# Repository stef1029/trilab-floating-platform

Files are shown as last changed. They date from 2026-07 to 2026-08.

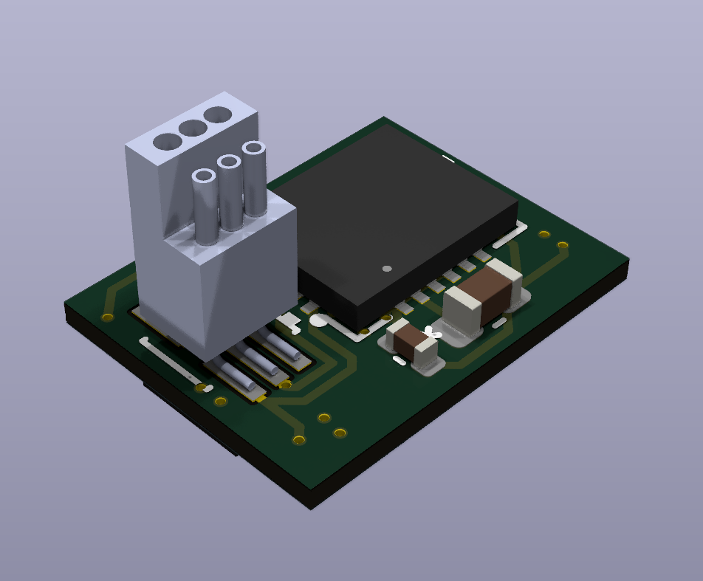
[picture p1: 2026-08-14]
assets/head_sensor_board_3d_model.png

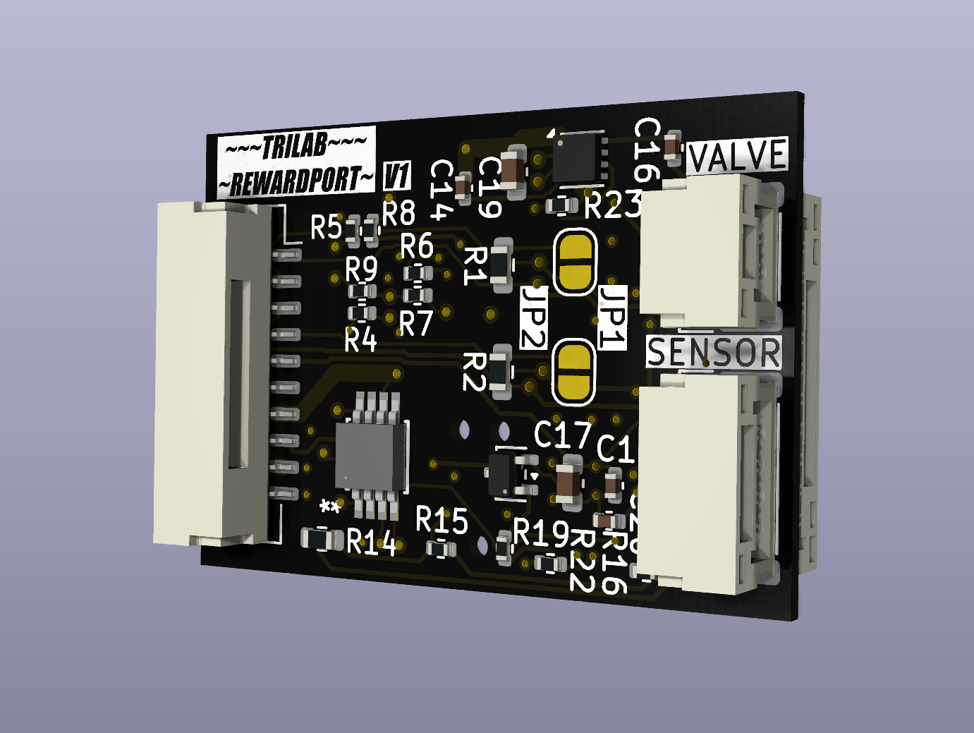
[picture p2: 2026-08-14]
assets/reward_port_3d_model.png

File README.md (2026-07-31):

# Floating Platform Orienting System — Project Specification

A head-fixed behavioural platform for studying sensory-guided spatial orienting in mice.

> **Status:** Design specification and prototyping. This readme defines the scientific intent,
> design principles, and requirements for the system.

---

## 1. Background and Motivation

### 1.1 The problem of spatial orienting

Orienting towards environmental stimuli is a fundamental behaviour conserved across the
animal kingdom: an animal turns its eyes, head, and body to bring a salient stimulus into
its sensory and motor focus. Although subjectively effortless, orienting requires the
nervous system to solve several hard computational problems at once:

- **Coordinate-frame transformation.** Different senses encode space in incompatible
  reference frames (vision in retinotopic coordinates, hearing in head-centred coordinates,
  touch in body-centred coordinates) yet the motor system needs a single unified target.
- **Sensorimotor transformation.** A spatial estimate must be converted into a coordinated
  motor command spanning effectors with very different dynamics (fast, low-range eyes; slower,
  wider-range head; slow, widest-range body).
- **Target selection.** When multiple stimuli compete, the system must commit to a single
  target, the body cannot turn two ways at once.

### 1.2 The superior colliculus (SC)

The SC is an evolutionarily ancient midbrain hub (circuits >500 My old) that sits at the
centre of this problem. It receives topographically aligned, convergent input from
essentially every sensory modality and contains a motor map from which electrical or
optogenetic stimulation reliably evokes orienting movements toward the corresponding
location. Beyond driving movement, accumulating evidence implicates the SC in **spatial
priority / attention**: it is thought to maintain a *priority map* that integrates bottom-up
salience with top-down task relevance, gating both descending orienting commands and
ascending thalamo-cortical signals.

### 1.3 The methodological gap this system addresses

Mouse genetics (Cre-driver lines, optogenetics, optotagging, calcium imaging, two-photon,
high-density electrophysiology) make the mouse SC uniquely tractable for circuit dissection.
But existing mouse paradigms force a trade-off:

| Approach | Strength | Weakness |
|---|---|---|
| **Head-fixed** (2-photon, Neuropixels, VR) | Maximal experimental control, high trial counts, recording/manipulation access | Sacrifices the natural whole-body orienting repertoire; reporting movements are abstract (e.g. licking, wheel turns) |
| **Freely moving** (escape, prey capture, social orienting) | Full natural movement repertoire, ethological validity | Low trial counts, behavioural adaptation/disengagement, hard to standardise and track, limited tool access |

**Design thesis:** a head-fixed preparation that *preserves rotational orienting kinematics*
by mounting the animal on a low-friction, air-floated platform can recover much of the
ethological character of orienting while retaining the recording/manipulation access and
trial structure of head fixation. This is the niche the floating platform system is intended
to fill. Closely related precedents exist in the ferret sound-localisation literature
(approach-to-target paradigms) and in air-lifted platform preparations for rodents; the
novelty here is combining controlled rotational orienting with head fixation and modern
mouse circuit tools.

> **Terminology.** This document follows the *orienting* vs *localisation* distinction
> (Nodal et al., 2008). *Orienting* is the unconditioned, continuously-varying movement of
> eyes/head/body toward a stimulus. *Localisation* (approach-to-target) is the conditioned
> report of perceived location via a discrete choice. This platform is designed to capture
> the **orienting movement itself as a continuous dependent variable**, not merely the
> categorical choice.

---

## 2. Scientific Design Principles

These principles flow directly from the science above and should govern every engineering
trade-off.

1. **Preserve orienting kinematics.** The animal must be able to produce naturalistic
   rotational orienting movements. The platform's mechanics (mass, inertia, friction) must be
   matched to mouse motor capability so that orienting is *natural and low-effort*, not a
   novel motor skill the animal must laboriously acquire. **Movement accessibility is a
   first-order scientific requirement, not an engineering nicety.**

2. **Multiple spatial targets.** Move beyond binary left/right. The animal must be able to
   orient toward stimuli distributed around it, so the system can probe the full spatial map
   of the SC.

3. **Movement as the primary readout.** The dependent variable is the *trajectory* of the
   orienting movement (bearing, latency, amplitude, velocity profile), not just an endpoint.
   This demands continuous, high-resolution measurement of platform orientation.

4. **Multimodal cueing.** Support visual and auditory cues (and ideally the means to add
   somatosensory), so cue modality and coordinate frame can be dissociated — central to
   testing how heterogeneous sensory inputs are transformed into a common motor currency.

5. **Recording- and manipulation-ready from day one.** The system exists to support
   electrophysiology, optogenetics/chemogenetics, and imaging. Compatibility with these tools
   — physical access, electromagnetic compatibility, and above all **temporal
   synchronisation** — must be designed in, not retrofitted.

6. **Trial structure and throughput.** Standardised, self-paced trials with clean
   trial/inter-trial separation, at counts sufficient for statistically powerful,
   circuit-level conclusions.

7. **Respect the animal.** Welfare-conscious head fixation and handling; training timelines
   that are realistic for a cohort within a project's lifetime.

---

## 3. Requirements

### 3.1 Functional requirements (behaviour)

- **F1 — Rotational freedom.** The mouse, while head-fixed, can rotate the floating platform
  beneath it to produce orienting movements through its full natural range, with friction low
  enough that movement is effortless.
- **F2 — Constrained degrees of freedom.** Platform motion is constrained to the behaviourally
  meaningful axes (rotation, translation).
- **F3 — Multi-target cueing.** Present discrete spatial cues at ≥4 (target: 6) locations
  distributed around the animal, with unambiguous angular separation.
- **F4 — Multimodal cues.** Independently addressable **visual** (per-location LED) and
  **auditory** (per-location or spatialised speaker) cue channels; spare capacity for a third
  modality.
- **F5 — Reward delivery.** Precise, low-latency liquid reward (calibrated µL volumes) at each
  target location, with reliable consumption detection.
- **F6 — Response detection.** Detect the animal's chosen orientation/target reliably and with
  low latency (event timing to ≤1 ms), with no false positives/negatives from the sensing
  modality.
- **F7 — Self-paced trial initiation.** A clear, animal-driven readiness/initiation event that
  separates trials from inter-trial intervals and standardises starting conditions.
- **F8 — Configurable protocol.** Cue duration, cue modality, target set, reward contingency,
  timeout, and inter-trial interval all configurable per session and per training phase,
  without code surgery.

### 3.2 Measurement requirements

- **M1 — Continuous orientation tracking.** Platform angular position sampled continuously at
  high temporal resolution (target ≥100 Hz, ideally faster) and angular precision sufficient
  to reconstruct full orienting trajectories — not just endpoints.
- **M2 — Absolute reference where possible.** Orientation measurement should resolve absolute
  bearing (not only relative drift), or provide robust per-trial re-zeroing against a known
  reference event.
- **M3 — Low-light operation.** Behaviour runs under controlled, mouse-appropriate lighting
  (e.g. long-wavelength / IR illumination); the tracking method must work under these
  conditions without motion blur or illumination that interferes with the visual task.
- **M4 — Video record.** Synchronised overhead and/or side video for behavioural scoring and
  markerless pose estimation.

### 3.3 Technical / systems requirements

- **T1 — Unified timing backbone (highest priority).** A single timing authority records all
  event streams — cue onset/offset, reward, response, orientation samples, video frame
  triggers, and external equipment (ephys/laser) sync — on one clock with **≤1 ms** alignment
  across streams. *Lack of hardware-level synchronisation is the single most likely failure
  mode of a behavioural-neuroscience rig and must be solved at the architecture level.*
- **T2 — Drop detection on every stream.** Every data stream (serial messages, camera frames)
  must carry sequence IDs / frame counters so that dropped samples are detectable and
  correctable post-hoc, never silently misaligning data.
- **T3 — External-equipment sync.** Generate and/or record TTL sync with electrophysiology
  acquisition and optogenetic laser control, so neural data and behaviour share a common time
  base.
- **T4 — Electromagnetic compatibility.** Construction and grounding compatible with
  electrophysiology (shielding / Faraday behaviour; low 50 Hz pickup; no conductive paths to
  electrodes).
- **T5 — Deterministic real-time control.** Time-critical operations (reward, response
  sensing, cue timing) handled with deterministic latency; high-level trial logic and logging
  separated from real-time control.
- **T6 — Automated session lifecycle.** One-command session start that configures and launches
  all subsystems (control, acquisition, cameras) in the correct order; automated logging with
  crash recovery.
- **T7 — Standardised, analysis-ready data.** Output to a documented, standard format (e.g.
  NWB) with an accompanying pipeline from raw streams → synchronised, trial-segmented dataset
  → quality-control metrics → figures, minimising manual steps.
- **T8 — Maintainability & reproducibility.** Modular, serviceable hardware (swappable
  per-target modules); liquid-tolerant construction; documented build so additional rigs can
  be replicated by the lab.
- **T9 — Session endurance.** Sustain a full behavioural session (target: continuous operation
  for multi-hour daily use) without power, thermal, or buffer constraints forcing early
  termination.

### 3.4 Non-functional requirements

- **N1 — Welfare.** Graduated head-fixation habituation; comfortable, low-stress fixation;
  bounded session durations.
- **N2 — Trainability.** A naïve mouse should reach criterion performance within a timeframe
  practical for a 10–12 animal cohort. *(Because mechanical accessibility (F1) directly
  governs trainability, the platform's inertia/friction budget should be validated against
  mouse motor output early.)*
- **N3 — Cost & scalability.** Favour designs that allow multiple rigs to run in parallel on
  shared infrastructure without duplicating the most expensive components.

---

## 4. Proposed System Description

A concrete architecture that satisfies the requirements above. Subsystems are described by
*function and constraints*; exact components are deliberately left open where the science does
not yet dictate them.

### 4.1 Mechanical core — the floating platform

- A lightweight, rigid platform (e.g. machined low-density foam) suspended on a **cushion of
  air** above a perforated, regulated air table, giving near-frictionless motion.
- Air supply regulated to lift the loaded platform (platform + onboard electronics) at a
  stable hover height with negligible residual friction.
- **Motion constrained** to the behaviourally relevant axes — primarily rotation (and
  optionally controlled fore/aft translation) — using physical guides, while blocking
  lateral/vertical excursions.
- **Inertia budget:** the rotational moment of inertia of the loaded platform must be small
  relative to the torque a mouse can comfortably generate. This is the central mechanical
  constraint and should be minimised (light platform, minimal onboard mass, balanced about the
  rotation axis) and validated empirically against mouse motor capability before committing.
- A low surrounding wall prevents falls without restricting movement and provides a mounting
  surface for cue/reward modules and/or tracking references.

### 4.2 Head-fixation assembly

- Standard, welfare-conscious head-bar fixation (off-the-shelf optomechanics) positioning the
  animal centrally over the platform's rotation axis, leaving the body free to drive platform
  rotation.
- Fixation height and posture chosen so that orienting is produced by natural weight-shift /
  stepping, not an artificial motor strategy.

### 4.3 Target / cue / reward modules

- A ring of **modular, independently serviceable target stations** at fixed angular intervals
  (target: 6 at 60°, minimum 4 at 90°).
- Each station integrates: a **visual cue** (high-brightness LED), an **auditory cue**
  (speaker), a **liquid reward** spout (solenoid/pinch-valve, gravity- or pump-fed, calibrated
  volume), and a **response/consumption sensor** (e.g. IR beam-break — preferred over
  capacitive sensing for reliability).
- Modularity allows a faulty station to be swapped without disturbing the rig and supports
  rapid prototyping of new configurations.

### 4.4 Orientation tracking

Continuous platform-orientation measurement is mandatory (M1–M3). The architecture should
support — and ideally fuse — complementary methods, chosen for robustness under low-light
operation:

- An **inertial measurement unit (IMU)** mounted on the platform for high-rate relative
  orientation, re-zeroed each trial against a known reference event (giving high within-trial
  accuracy).
- And/or an **absolute optical reference** (e.g. fiducial markers read by a camera, or an
  optical/magnetic angular encoder on the rotation axis) for absolute bearing and drift
  correction — noting that any camera-based method must tolerate the IR/low-light regime and
  platform motion without blur.
- **Markerless pose estimation** (e.g. DeepLabCut) on synchronised video as an independent
  cross-check and for body/limb kinematics.

### 4.5 Control and acquisition architecture

The defining architectural commitment: **separate real-time control from timing/logging.**

- **Real-time controller** (microcontroller): owns deterministic, time-critical hardware
  control — cue timing, reward actuation, response sensing — and nothing else. Prefer a
  microcontroller with **native USB** (low, deterministic serial latency) over legacy
  serial-to-USB bridges.
- **Independent acquisition / timing backbone (DAQ):** a dedicated device that does nothing
  but sample *all* digital/analogue lines (cue states, sensor states, reward signals) plus
  external sync (camera frame TTLs, ephys clock, laser control) at high rate (target ≥1 kHz,
  ideally ≥10 kHz) onto **one clock**. Every message carries a sequence ID (T2).
- **Host computer:** runs high-level trial logic / state machine, configuration, multi-rig
  orchestration, real-time performance metrics, and all file writing (offloading I/O from
  embedded devices). Launches the whole session with one command (T6).
- **Cameras:** programmatically controlled (not via a GUI), emitting a TTL per frame into the
  DAQ and saving hardware frame IDs, so dropped frames are detectable and video aligns to the
  behavioural timeline to the frame.

This separation is what delivers T1–T3: a single timestamped record into which neural,
video, and behavioural events all map without clock drift.

### 4.6 Software, data, and analysis pipeline

- **Configurable protocol engine** encoding training phases and trial parameters via
  configuration, not code edits (F8).
- **Standardised output** (NWB or equivalent) bundling synchronised event streams, orientation
  traces, video references, and trial metadata, with crash-recovery/backup.
- **Automated post-processing**: parse DAQ logs → reconstruct trials → align video via frame
  IDs → run pose estimation → emit a trial-segmented dataset plus QC metrics, with minimal
  manual intervention.
- **Cohort/session data model** giving programmatic access (query by animal, date, completion
  status) so analyses run over whole cohorts in little code.

### 4.7 Behavioural protocol (intended)

1. **Initiation.** The animal produces a defined, self-paced readiness event that standardises
   the starting orientation and separates trials from inter-trial intervals (F7). The
   initiation requirement must be designed to genuinely standardise starting conditions
   (minimising preparatory movement before cue onset).
2. **Cue.** One target is cued (visual and/or auditory), with configurable duration.
3. **Orienting response.** The animal rotates the platform to bring the cued target into
   reach; the full trajectory is recorded.
4. **Outcome.** Correct orientation → immediate calibrated reward. Incorrect → brief timeout,
   no reward.
5. **Reset.** Return to initiation for the next self-paced trial.

---

## 5. Key Open Design Questions / Risks

Flagged up front because they drive the riskiest decisions:

- **Mechanical accessibility vs. control (F1/N2).** Can the inertia/friction budget be made
  low enough that a head-fixed mouse produces natural orienting rotations *and* learns the task
  in a cohort-feasible timeframe? This is the make-or-break biological-mechanical question and
  should be de-risked first with simple motor-capability tests.
- **Tracking under low light (M1–M3).** Reconciling absolute, blur-free, high-rate orientation
  measurement with the dim/IR lighting the visual task requires. IMU + absolute-encoder fusion
  is the conservative hedge.
- **Initiation standardisation (F7).** Defining an initiation behaviour that truly fixes
  starting orientation without permitting covert preparatory movement.
- **Synchronisation throughput (T1).** Achieving the target sample/frame rates without
  message loss; choice of controller and DAQ should leave headroom above the minimum.

---

## 6. Key References

Foundational citations that justify the design intent.

**Superior colliculus, orienting, and spatial priority**
- May, P. J. (2006). The mammalian superior colliculus: laminar structure and connections.
  *Prog. Brain Res.* 151. — SC anatomy and laminar organisation.
- Sparks, D. L. & Mays, L. E. (1990). Signal transformations required for the generation of
  saccadic eye movements. *Annu. Rev. Neurosci.* 13. — SC sensorimotor transformation.
- Fecteau, J. H. & Munoz, D. P. (2006). Salience, relevance, and firing: a priority map for
  target selection. *Trends Cogn. Sci.* 10. — priority-map concept.
- Krauzlis, R. J., Lovejoy, L. P. & Zénon, A. (2013). Superior colliculus and visual spatial
  attention. *Annu. Rev. Neurosci.* 36. — SC role in attention beyond movement.
- Knudsen, E. I. (2018). Neural circuits that mediate selective attention: a comparative
  perspective. *Trends Neurosci.* 41. — gating and selective attention.
- de Malmazet, D. & Tripodi, M. (2023). Collicular circuits supporting the perceptual, motor
  and cognitive demands of ethological environments. *Curr. Opin. Neurobiol.* 82.
- Masullo, L. et al. (2019). Genetically defined functional modules for spatial orienting in
  the mouse superior colliculus. *Curr. Biol.* 29. — Pitx2+ SC output neurons; target
  population for manipulation.

**Behavioural paradigms and precedents**
- Parsons, C. H., Lanyon, R. G., Schnupp, J. W. H. & King, A. J. (1999). *J. Neurophysiol.* 82.
  — ferret sound-localisation / approach-to-target precedent.
- Nodal, F. R. et al. (2008). Sound localisation behaviour in ferrets: acoustic orientation vs
  approach-to-target. *Neuroscience* 154. — the orienting vs localisation distinction.
- Robbins, T. W. (2002). The 5-choice serial reaction time task. *Psychopharmacology* 163. —
  multi-choice spatial reporting paradigm.
- Guo, Z. V. et al. (2014). Procedures for behavioral experiments in head-fixed mice. *PLoS
  ONE* 9. — head-fixed behavioural standards.
- Kislin, M. et al. (2014). Flat-floored air-lifted platform: combining behaviour with
  microscopy/electrophysiology on awake freely moving rodents. *JoVE*. — air-lifted platform
  precedent.
- Angelaki, D. et al. (2025). A brain-wide map of neural activity during complex behaviour.
  *Nature* 645. — mice performing complex standardised tasks.

**Tools and infrastructure**
- Denman, D. J. et al. (2017). Chromatic pathways in the mouse dLGN. *J. Neurosci.* 37. —
  basis for long-wavelength lighting choices for mouse vision.
- Mathis, A. et al. (2018). DeepLabCut: markerless pose estimation. *Nat. Neurosci.* 21.
- Rübel, O. et al. (2022). The Neurodata Without Borders ecosystem. *eLife* 11. — standardised
  data format.

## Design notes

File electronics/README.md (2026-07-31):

# Electronics

KiCad projects, schematics, PCB layouts, BOMs, and fabrication outputs.

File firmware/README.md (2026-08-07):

# Korora Fairy system

This project contains contains firmware for one Korora, one Galapagos, and a configurable number of Fairy boards. It also contains the Adelie Python application and the shared wire protocol library.

The default maximum is six Fairy boards. Change `FAIRY_MAX_BOARDS` in `shared/include/fairy_shared/system_config.hpp` or pass it as a build definition.

## Naming conventions

| Implementation name | Role | Board |
| --- | --- | --- |
| Korora | Floating platform hub | nRF52840 |
| Fairy | Reward port | STM32G071\* |
| Galapagos | Static DAQ TTL sync | nRF54L15 |

| Protocol name | Layer | Use |
| --- | --- | --- |
| Fairy protocol | Application | Defines structure of records that are collected and used for later analysis |
| Adelie protocol | Application | Defines structure of commands being issued for interaction with peripherals, generating TTLs... |
| Magellan protocol  | Application | Defines process and structure of assinging logical addresses to fairy boards |
| Transport protocol | Transport | Defines the structure of frames being sent over various media (UART, BLE) |

## System structure

```mermaid
flowchart TD
    A["Adelie Python application"] <-->|"BLE transport"| K["Korora nRF52840"]
    K <-->|"BLE transport"| G["Galapagos nRF54L15"]
    K <-->|"RS485 transport"| F["Fairy boards"]
    K -->|"4 Hz SYNC"| F
    G -->|"TTL loopback"| K
```

Korora is the time authority and the only RS485 bus master. Galapagos creates scheduled TTL pulses. Fairy boards capture light gate and SYNC edges and drive the local outputs. Adelie assigns board names, sends commands, displays live quality, and writes experiment records.

All machine data uses one of these application protocols:

- Fairy v3 for records
- Adelie v2 for commands and responses
- Magellan v1 for discovery and address assignment

The application messages always use Transport v1 on BLE or RS485. Human debug text is isolated in each `debug_log` module and is never parsed by the system.

## Folders

| Folder | Purpose |
| --- | --- |
| `shared` | C++ transport, protocol, clock, queue, and byte utilities |
| `korora` | Zephyr firmware for the nRF52840 hub |
| `galapagos` | Zephyr firmware for the nRF54L15 TTL board |
| `fairy` | STM32Cube and PlatformIO firmware for STM32G071 boards |
| `adelie` | Python 3.14 control, recording, parsing, analysis, and plotting |
| `docs` | Wire protocol specifications and operating rules |

## Fixed timing values

| Setting | Value |
| --- | ---: |
| Common timestamp rate | 16000000 ticks per second |
| SYNC rate | 4 Hz |
| RS485 baud | 460800 |
| RS485 format | 8 data bits, no parity, 1 stop bit |
| Fairy TIM2 rate | 16 MHz |
| Prototype VLOAD | 5000 mV |

One timer tick is 62.5 ns.

## Build summary

Use a current Zephyr or nRF Connect SDK workspace for the Nordic firmware.

```bash
west build -p always -b nrf52840dk/nrf52840 korora
west flash
```

```bash
west build -p always -b nrf54l15dk/nrf54l15/cpuapp galapagos
west flash
```

Build the prototype Fairy firmware with PlatformIO.

```bash
pio run -d fairy -e nucleo_g071rb_auto_rs485
pio run -d fairy -e nucleo_g071rb_auto_rs485 -t upload
```

Install Adelie in a Python 3.14 virtual environment.

```bash
cd adelie
python -m venv .venv
python -m pip install -e .
adelie
```

## Initial setup

1. Power Korora, Galapagos, and all Fairy boards
2. Start Adelie and connect to Korora
3. Wait for the complete UUID inventory
4. Use White LED to identify each board
5. Give each UUID a unique zero based Fairy index
6. Save the exact configuration
7. Wait for every clock model to become valid
8. Choose a new `.log` path
9. Press Record Start

Adelie applies saved assignments automatically only when the complete discovered UUID set exactly matches the saved set. A missing, added, or replaced board returns the user to configuration.

## Run behavior

Korora starts discovery, health checks, RS485 polling, and SYNC without Adelie. It does not save experiment data.

Record Start creates a session on every board. An unexpected Adelie disconnect ends that session and turns controlled outputs safe. Discovery, SYNC, and health work continue until power is removed.

A Fairy communication timeout or a Galapagos disconnect also ends the complete session. The fault is sent to Adelie before the remaining boards are stopped.

Critical records are always forwarded. Standard mode adds health and clock quality. Full mode adds raw SYNC observations and clock pairs.

## Safety

The valve starts off and has a hard 250 ms maximum time. It rejects overlap and enforces a minimum interval. RGB, IR, audio, and valve outputs enter safe states on reset and session stop. Audio has a 10 ms onset and offset ramp. The prototype configuration assumes automatic RS485 direction control. Korora and the Nucleo profile do not drive a direction GPIO.

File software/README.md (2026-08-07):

# Adelie Python application

Adelie is the universal host application for board setup, live control,
recording, static analysis, and plotting. It is written for Python 3.14 and
also supports Python 3.11 or newer.

## Features

- Bleak connection to Korora
- Modern PySide6 interface
- One live card per Korora, Galapagos, and Fairy
- Live RMS history, skew, record rate, queue, loss, and RSSI
- Exact UUID configuration saved as JSON
- White LED board identification
- RGB, IR, tone, white noise, and valve controls
- Telemetry level selection
- Scheduled TTL train control
- One button sync test
- One locked JSON Lines log writer
- Static parser, analyser, and plotter

## Install

```bash
python -m venv .venv
python -m pip install --upgrade pip
python -m pip install -e .
```

Run:

```bash
adelie
```

Optional paths:

```bash
adelie --config config/boards.json --recordings recordings
```

## Board configuration

Adelie requests the full live inventory after BLE connects.

When the saved UUID set matches exactly, Adelie sends the saved Fairy indices
to Korora. When it differs, the table remains in configuration mode.

To create a configuration:

1. Click White LED on one row
2. Find the board showing white
3. Enter its zero based Fairy index and label
4. Repeat for every row
5. Save the exact UUID configuration

The JSON file is the backup. Korora stores no assignment across a power cycle.

If any live UUID is added, missing, or replaced, automatic assignment stops.

## Recording

Choose the `.log` path before Record Start. The recorder creates a new file
and refuses to overwrite an existing file.

Each line is one JSON value. The file contains:

- Header with protocol versions and UUID mapping
- Every Fairy record received during the session
- Raw application message in Base64
- Host monotonic receive time
- Footer with stop reason

Nothing is written before Record Start. An unexpected BLE disconnect closes
the file with a footer when the process still has control.

Record Stop keeps the writer open briefly after the stop response so final
output off records can arrive. A Fairy inventory change or a critical hardware
fault requests the same orderly stop.

## Telemetry

Critical mode keeps experiment events and faults.

Standard mode also keeps health, inventory, link, and clock quality.

Full mode also keeps every raw SYNC observation and clock pair. Test sync
selects full mode, sends safe random RGB commands, and starts TTL at 1 Hz.

## Static tools

Run the full pipeline:

```bash
adelie-run-analysis recordings/run_20260730_120000.log
```

Or run each stage:

```bash
adelie-parse RUN.log
adelie-analyse RUN_parsed
adelie-plot RUN_parsed
```

The parser creates:

- `records.csv`
- `commands.csv`
- `command_results.csv`
- `sync_pairs.csv`
- `sync_quality.csv`
- `ttl.csv`
- `events.csv`
- `health.csv`
- `manifest.json`

The analyser creates:

- `node_summary.csv`
- `command_summary.csv`
- `prediction_errors.csv`
- `ttl_results.csv`
- `summary.json`
- `summary.txt`

The plotter creates synchronization, per node prediction error, command RTT,
and TTL alignment PNG files when the required records exist.

Every parsed record includes its numeric logical address, logical node name,
saved label, and Fairy index. For example, address `0x10` is reported as
`fairy0` rather than a generic node number.

`commands.csv` contains one row per Adelie command with:

- Time waiting in the host transmit queue
- Queue to response RTT
- Actual BLE send to response RTT
- Destination logical node
- Opcode and response status
- Missing response detection
- Matching command result count and result nodes
- Clock exchange full RTT, Korora processing time, and network RTT

`command_results.csv` matches Fairy command result records back to the Adelie
command ID and reports them separately for every logical Fairy.

Command timing fields are available only in logs recorded with this version of
Adelie. Older logs did not store outbound command or response timestamps, so
their command RTT cannot be reconstructed.

## Log recovery

Every record is one complete flushed line. If the host loses power, valid
lines before the partial final line remain usable. The parser reports the
line number of malformed JSON so a partial last line can be removed without
changing earlier data.

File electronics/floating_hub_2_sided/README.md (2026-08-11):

# Korora Hub

Central nRF52840-based hub board for the behavioural rig. Korora provides:

- RS-485 master communication to peripheral boards
- Differential SYNC distribution to peripheral boards
- System time authority and synchronization
- 9-DoF motion/orientation sensing
- LiPo battery charging and power-path management
- Battery / power telemetry to the nRF52840
- 3V3 and VLOAD distribution over the peripheral harness
- USB/SWD-style development and debug access as appropriate for the final PCB

The current controller module is the BMD-340-A-R, based on the nRF52840.

The current power-management assumption is an nPM1300-class Nordic PMIC. Exact PMIC variant, battery connector, thermistor arrangement, charge current, and rail configuration must be finalized against the selected battery before schematic release.

## System architecture

Korora is the system master.

The hub:

- owns the system timebase
- initiates RS-485 transactions
- emits the differential SYNC signal
- gathers peripheral event timestamps
- translates peripheral-local timestamps into hub/system time
- acquires the local IMU and magnetometer
- runs or hosts the 9-DoF orientation-fusion algorithm
- monitors battery and power state
- distributes 3V3, VLOAD, and ground to the peripheral chain

Initial high-level architecture:

```text
                         +----------------------+
5V BENCH INPUT --------->|                      |
                         |       nPM PMIC       |
LiPo BATTERY ----------->| charger / fuel gauge|
                         | power-path / bucks   |
                         +----+-------------+---+
                              |             |
                             3V3           VSYS
                              |             |
                              |             +---------- VLOAD
                              |                         |
                              +-------------------------+--> JST-GH
                              |
                    +---------+---------+
                    |    BMD-340-A-R    |
                    |      nRF52840     |
                    +----+----+----+----+
                         |    |    |
                      UART   GPIO  I2C/SPI
                         |    |    |
                         |    |    +----> IMU
                         |    |    +----> magnetometer
                         |    |    +----> PMIC telemetry
                         |    |
                         |    +---------> SN65HVD75 #2
                         |                  SYNC_P/N
                         |
                         +-------------> SN65HVD75 #1
                                            RS485_P/N
```

## Relationship to peripheral boards

Korora is designed to connect directly to peripheral boards using the common 10-pin JST-GH bus.

Korora is the RS-485 bus master and the source of the differential SYNC pulse. Peripheral boards are expected to:

- listen for hub commands
- transmit only when addressed
- capture SYNC locally in hardware
- report captured timestamps and local events back to Korora

The initial Reward Port design assumes a 500000 baud, 8-N-1, half-duplex RS-485 link and an initially 4 Hz SYNC pulse.

These values are initial protocol parameters rather than permanent electrical limitations.

## Power inputs

Korora has two power sources:

1. LiPo battery
2. External 5 V bench / development supply

The PMIC provides charging and power-path control between them.

### Battery input

The earlier system requirement described the battery as approximately 4.3 V.

Do not set the PMIC charge termination voltage from that description alone. The final battery datasheet controls:

- maximum charge voltage
- charge current
- temperature limits
- NTC requirements
- minimum discharge voltage
- protection requirements

### Bench power input

Provide a 2-pin header for development power:

| Pin | Signal |
| --: | --- |
| 1 | +5V_BENCH |
| 2 | GND |

The bench input feeds the PMIC input rather than directly feeding the battery rail.

Intended behaviour:

```text
5 V bench present
        |
        v
      PMIC
      /  \
     /    +----> system load
    |
    +---------> battery charging
```

The bench supply must be current limited during initial bring-up.

## Power rails

Korora distributes two positive rails to the peripheral connector.

### 3V3

3V3 is the regulated digital rail.

Expected loads include:

- BMD-340-A-R
- RS-485 transceivers
- local sensors
- PMIC digital interface as required
- peripheral-board 3V3 loads through the JST-GH chain

The total required 3V3 current is TBD.

Before finalizing the PMIC configuration, calculate:

```text
hub local 3V3 load
+
maximum number of peripheral boards
x
maximum peripheral 3V3 load
=
required regulated 3V3 current
```

If this exceeds the useful continuous current available from the selected PMIC regulator configuration, Korora requires an external 3V3 regulator or a revised power architecture.

### VLOAD

VLOAD is currently defined as the PMIC system / VSYS rail.

VLOAD is not assumed to be a precision regulated 5 V rail.

Conceptually:

```text
battery operation:
battery -> PMIC power path -> VSYS -> VLOAD

bench operation:
5 V input -> PMIC power path -> VSYS -> VLOAD
```

Therefore VLOAD may vary with power-source state and battery condition.

Peripheral loads must be designed for the specified VLOAD operating range.

The final VLOAD voltage range and current limit must be documented after the PMIC and battery design are finalized.

## PMIC interface

Korora should provide a digital control / telemetry link between the PMIC and the nRF52840.

Current intended interface:

```text
BMD-340 SDA <------> PMIC SDA
BMD-340 SCL -------> PMIC SCL
PMIC IRQ ----------> BMD-340 GPIO
```

The firmware should be able to query and log, where supported by the selected PMIC configuration:

- battery voltage
- battery current
- input-source state
- charging state
- state of charge
- battery health / aging information
- PMIC fault state
- regulator state
- power-loss or low-battery warnings

Exact registers and reported metrics depend on the final PMIC implementation.

## Main controller

Controller module:

```text
BMD-340-A-R
nRF52840
```

Korora uses the nRF52840 for:

- system timing
- RS-485 protocol
- SYNC generation
- peripheral discovery and polling
- event collection
- sensor acquisition
- sensor fusion
- battery telemetry
- BLE / radio functionality if required
- diagnostics
- firmware update / development functions

## BMD-340 pin assignment

Physical BMD-340 pin numbers are not yet frozen.

Reserve logical functions for:

| Function | Peripheral / type | Notes |
| --- | --- | --- |
| RS-485 transmit | UARTE TX | Main peripheral bus |
| RS-485 receive | UARTE RX | Main peripheral bus |
| RS-485 driver enable | GPIO or UARTE DE strategy  | Must default bus-safe |
| SYNC output | GPIO / timer-driven output | Feeds second RS-485 driver |
| PMIC SDA | TWIM / I2C | Shared bus possible |
| PMIC SCL | TWIM / I2C | Shared bus possible |
| PMIC interrupt | GPIO input | Optional but recommended |
| IMU bus | SPI or I2C | Final choice TBD |
| IMU interrupt 1 | GPIO input | Data-ready / FIFO event |
| IMU interrupt 2 | GPIO input | Optional |
| Magnetometer bus | I2C or SPI | Final choice TBD |
| Magnetometer DRDY | GPIO input | Optional but recommended |
| SWDIO | SWD | Debug |
| SWDCLK | SWD | Debug |
| RESET | reset | Debug / recovery |

The final pin assignment should be chosen only after confirming:

- BMD-340 pin availability
- nRF52840 peripheral routing
- high-frequency / antenna placement constraints
- PCB routing
- sensor interrupt requirements
- boot and debug requirements

## RS-485 data bus

Korora uses one SN65HVD75DGKR for the main half-duplex RS-485 bus.

Logical connections:

```text
BMD UARTE_TX ---------> SN65HVD75 D
BMD UARTE_RX <--------- SN65HVD75 R
BMD RS485_DE ---------> SN65HVD75 DE
                       SN65HVD75 /RE
                              |
                              +---- RS485_P
                              +---- RS485_N
```

Exact DE and /RE wiring is TBD.

The design must guarantee that Korora does not unintentionally drive the bus during reset or boot.

Initial protocol configuration inherited from the first Reward Port:

```text
500000 baud
8 data bits
no parity
1 stop bit
half duplex
hub master polling
peripherals transmit only when addressed
```

Korora is the only normal bus master.

## Differential SYNC output

Korora uses a second SN65HVD75DGKR as a dedicated differential digital-output driver.

Concept:

```text
BMD SYNC GPIO --------> SN65HVD75 D
                             |
                             +---- SYNC_P
                             +---- SYNC_N
```

Korora is the source of SYNC.

Peripheral boards receive the differential pair and convert it back to a local logic signal for hardware timer capture.

Initial SYNC frequency:

```text
4 Hz
```

The exact pulse width is TBD.

The SYNC waveform should be generated from a hardware timer or hardware-timed GPIO mechanism where practical so that edge timing does not depend on normal firmware scheduling latency.

SYNC_P / SYNC_N provide differential signalling and noise immunity.

They do not by themselves provide authentication or cryptographic security.

## System time

Korora is the system time authority.

The design currently assumes:

- no distributed high-frequency TIMEBASE line
- peripheral boards keep their own local hardware timers
- Korora periodically emits SYNC
- peripherals hardware-capture the SYNC edge
- peripherals report the captured local timestamp
- Korora estimates the mapping between peripheral-local time and hub time

Korora should maintain a monotonic high-resolution local clock suitable for:

- command timestamps
- peripheral event timestamps
- sensor timestamps
- SYNC generation
- logging
- session-relative time

## Daisy-chain connector

Korora uses the same 10-pin JST-GH pinout as the peripheral boards.

| Pin | Signal  |
| --: | --- |
| 1 | RS485_P |
| 2 | RS485_N |
| 3 | SYNC_P  |
| 4 | SYNC_N  |
| 5 | 3V3 |
| 6 | GND |
| 7 | VLOAD |
| 8 | GND |
| 9 | VLOAD |
|  10 | GND |

Pins 7 and 9 are the same VLOAD net.

Pins 6, 8, and 10 join the same ground system.

Korora will normally be one physical end of both differential buses.

Therefore the hub should include termination provisions for:

- RS485_P to RS485_N
- SYNC_P to SYNC_N

Preferred implementation:

```text
optional 120 ohm RS-485 termination
optional 120 ohm SYNC termination
```

using solder jumpers or clearly defined assembly options.

Only the physical ends of each differential bus should be terminated.

## Connector current distribution

The duplicated VLOAD and GND pins are intended to reduce harness resistance and increase available load-current capacity.

Before schematic release, define:

- JST-GH contact current assumptions
- cable wire gauge
- cable length
- maximum number of daisy-chained peripherals
- maximum simultaneous peripheral current
- VLOAD transient current
- allowed voltage drop
- ground-return distribution

Do not use connector nominal current ratings alone as the system current budget.

The complete cable and connector chain must be checked.

## Local 9-DoF sensing

Korora contains:

```text
6-axis IMU:
STEVAL-MKI240KA during development
LSM6DSV32X sensor

3-axis magnetometer:
MMC5983MA / MMC5983MA-B development hardware
```

Combined measurements:

```text
accelerometer:  X Y Z
gyroscope:      X Y Z
magnetometer:   X Y Z

total: 9 axes
```

Initial requested fused update rate:

```text
20 Hz to 100 Hz
```

This is the output / processing rate target, not necessarily the raw sensor sampling rate.

Raw accelerometer and gyroscope data may be sampled faster and decimated or fused into a 20-100 Hz application output.

## Sensor interface

Final electrical bus allocation is TBD.

Two reasonable starting configurations are:

```text
Option A:
IMU           -> SPI
magnetometer  -> I2C
PMIC          -> I2C

Option B:
IMU           -> I2C
magnetometer  -> I2C
PMIC          -> I2C
```

Option A gives the IMU a dedicated high-throughput bus.

Option B minimizes routing and is likely sufficient for the initial 20-100 Hz application rate.

During prototype bring-up, use the interfaces exposed by the available evaluation boards.

The final integrated PCB should use the sensor IC interfaces directly unless there is a deliberate reason to retain plug-in modules.

## Sensor interrupts

Prefer hardware data-ready interrupts rather than polling for timing-sensitive sensor acquisition.

Recommended signals:

```text
IMU INT1 -------> BMD GPIO
IMU INT2 -------> BMD GPIO    optional
MAG DRDY -------> BMD GPIO    if available / useful
```

Firmware should timestamp sensor-ready events against the same hub timebase used for the rest of the system.

## Sensor fusion

The initial 9-DoF processing goal is orientation tracking.

Expected outputs may include:

- orientation quaternion
- roll
- pitch
- yaw / magnetic heading
- angular velocity
- linear acceleration estimate
- sensor quality / calibration state

Candidate fusion approaches include:

- Madgwick
- Mahony
- complementary-filter variants
- extended Kalman filter

The exact algorithm is TBD.

The first implementation should prioritize:

- stable timestamps
- deterministic sample cadence
- accelerometer calibration
- gyroscope bias calibration
- magnetometer hard-iron calibration
- magnetometer soft-iron calibration
- sensor-axis alignment

## Position-tracking limitation

The 9-DoF sensor stack does not by itself provide stable long-term absolute XYZ position.

Double integration of accelerometer error causes position drift.

Therefore the current hub requirements should distinguish between:

```text
orientation / motion tracking
```

and:

```text
absolute or long-term XYZ position tracking
```

If absolute position is later required, Korora will need an external position reference such as:

- UWB
- optical tracking
- GNSS for suitable outdoor use
- fixed beacons
- application-specific mechanical constraints

This is a system-level requirement and should be resolved before relying on the IMU as a position sensor.

## Sensor placement

The IMU and magnetometer require deliberate PCB placement.

### IMU

Place the IMU:

- on mechanically stable PCB area
- away from board edges that flex
- away from high-vibration switching components where practical
- with a documented sensor-to-board axis convention

Mark the sensor axes in the schematic notes and PCB documentation.

### Magnetometer

The magnetometer is sensitive to local magnetic fields.

Keep it as far as practical from:

- inductors
- high-current VLOAD traces
- battery-current loops
- speakers
- solenoids
- ferromagnetic fasteners
- large copper current loops
- switching regulators

The preferred magnetometer location is likely near a PCB edge with a controlled keepout from magnetic / high-current components.

Final placement should be validated experimentally.

## Antenna placement

The BMD-340-A-R antenna area must be treated as an RF keepout.

Final PCB layout must follow the module manufacturer's antenna-placement requirements.

In particular, do not allow the power section, battery, magnetometer, high-current harness routing, or large copper structures to compromise the antenna region.

Place the BMD-340 near a suitable board edge unless the final RF design intentionally uses a different approved arrangement.

## Debug and programming

Provide access to at least:

```text
SWDIO
SWDCLK
RESET
3V3 reference
GND
```

Preferred implementation is a compact Tag-Connect footprint, pogo-pad pattern, or small debug header.

Also provide useful test points for:

- 5V_BENCH
- battery positive
- VSYS / VLOAD
- 3V3
- RS485_DE
- UART TX
- UART RX
- SYNC logic signal
- PMIC interrupt
- sensor interrupt lines

## Firmware responsibilities

Korora firmware is responsible for:

- boot-time safe-state configuration
- PMIC initialization
- battery monitoring
- monotonic system time
- differential SYNC generation
- peripheral discovery
- RS-485 master arbitration
- command transmission
- response validation
- peripheral clock translation
- event aggregation
- IMU acquisition
- magnetometer acquisition
- sensor calibration
- sensor fusion
- local logging / diagnostics
- radio or host communication if enabled
- watchdog handling
- low-battery behaviour

## RS-485 master behaviour

Initial bus behaviour:

1. Korora owns the bus.
2. Korora addresses one peripheral.
3. The addressed peripheral may respond.
4. Unaddressed peripherals remain receive-only.
5. Korora detects response timeout or malformed response.
6. Korora continues polling according to the active session configuration.

The protocol still needs definitions for:

- peripheral address format
- discovery
- message framing
- CRC
- command IDs
- session IDs
- timestamp format
- timeout
- retries
- fault reporting
- firmware / hardware version reporting

## SYNC behaviour

Initial sequence:

1. Start the hub monotonic clock.
2. Configure SYNC output hardware.
3. Emit SYNC at the configured cadence.
4. Record the hub timestamp associated with each emitted edge.
5. Poll peripherals for their captured local SYNC timestamps.
6. Estimate local-to-hub clock offset and rate.
7. Mark a peripheral unsynchronized when the estimate becomes invalid.

The first peripheral README assumes an initial 4 Hz SYNC rate.

The final rate should be chosen from measured oscillator drift, event-timing requirements, bus traffic, and desired recovery time after connection.

## Battery and low-power behaviour

Low-battery policy is TBD.

Firmware should eventually define thresholds for:

- warning
- reduced functionality
- peripheral VLOAD shutdown if hardware supports it
- radio behaviour
- safe session termination
- final shutdown

Do not allow an uncontrolled battery collapse to be the normal session-ending mechanism.

## Fault handling

Korora should detect and log at least:

- PMIC fault
- low battery
- charger fault
- missing sensor
- IMU communication fault
- magnetometer communication fault
- invalid sensor calibration
- RS-485 timeout
- RS-485 framing / CRC error
- peripheral missing
- peripheral synchronization loss
- watchdog reset
- brownout reset

Where useful, store reset cause and fault state across reboot.

## Startup order

Recommended initial startup order:

1. Keep RS-485 driver disabled.
2. Keep SYNC output in a defined inactive state.
3. Configure clocks and the hub monotonic timer.
4. Initialize watchdog and reset-cause logging.
5. Initialize PMIC communication.
6. Verify 3V3 and power-source state.
7. Initialize IMU communication.
8. Initialize magnetometer communication.
9. Load or initialize sensor calibration.
10. Initialize RS-485 UART and driver-enable control.
11. Start SYNC generation.
12. Discover peripheral boards.
13. Establish synchronization state.
14. Start sensor acquisition and fusion.
15. Enter the normal polling / session loop.

The system must not allow accidental RS-485 transmission while the nRF52840 pins are still in reset/default state.

## Shutdown behaviour

Recommended controlled shutdown sequence:

1. Stop issuing new peripheral actions.
2. Tell peripherals to enter safe state where applicable.
3. Flush critical logs.
4. Mark session end.
5. Stop or disable VLOAD if the final hardware supports switched VLOAD.
6. Configure wake sources.
7. Enter low-power mode or PMIC-controlled shutdown.

Exact behaviour is TBD.

## Open hardware decisions

The following items are not yet frozen:

- exact nPM PMIC part / package
- exact LiPo cell
- battery connector
- NTC implementation
- charge current
- 3V3 total current requirement
- whether an external 3V3 regulator is required
- whether VLOAD is always-on VSYS or switchable
- maximum VLOAD current
- number of supported peripheral boards
- exact BMD-340 GPIO mapping
- RS-485 DE / /RE wiring
- RS-485 and SYNC protection components
- SYNC pulse width
- sensor bus selection
- whether eval boards are only prototypes or remain pluggable
- final IMU part implementation
- final magnetometer part implementation
- antenna / enclosure constraints
- debug connector style
- host / USB interface requirements

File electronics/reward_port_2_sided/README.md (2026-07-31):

# Reward Port

Standalone STM32G071-based reward port controller for a behavioural rig. Each reward port provides:

- Differential RS-485 communication with the hub
- Differential SYNC input with hardware timestamp capture
- Omron EE-SX1140 light-gate capture
- RGB visual cue output
- Band-limited noise playback
- Lee LHDB0342115H solenoid valve control
- Local event buffering and clock translation

The final PCB uses an STM32G071GBU6 in a UFQFPN-28 package. The wired prototype uses a NUCLEO-G071RB with an STM32G071RBT6 (see [prototype wiring](PROTOTYPE.md)). Both use the same STM32G0 peripheral architecture, although the PCB and Nucleo GPIO pin assignments differ.

## System architecture

The nRF52840 hub is the system time authority and RS-485 bus master. The reward port has its own local timer. There is no external oscillator, distributed TIMEBASE, or TCXO.

The hub periodically emits a differential SYNC pulse, initially at 4 Hz. Each reward port captures the pulse using TIM2 hardware input capture. The reward port reports its captured local timestamp to the hub.

## Power rails

The reward port receives:

- 3V3 for the STM32 and communication transceivers
- VLOAD for the solenoid, audio amplifier, and RGB LED; during development this may be supplied from the 5 V dev-board rail
- Ground

## Final MCU pin assignment

| Function | GPIO | UFQFPN-28 pin | Peripheral  |
| --- | ---: | ---: | --- |
| Differential SYNC capture |  PA0 | 6 | TIM2_CH1 |
| Light-gate capture |  PA1 | 7 | TIM2_CH2 |
| Audio amplifier shutdown |  PA2 | 8 | GPIO output |
| IR emitter enable |  PA3 | 9 | GPIO output |
| Audio waveform |  PA4 | 10 | DAC1_OUT1 |
| Light-gate analogue measurement |  PA6 | 12 | ADC_IN6 |
| RGB channel 3 |  PB0 | 14 | TIM3_CH3 |
| Solenoid PWM |  PA8 | 16 | TIM1_CH1 |
| SWD data | PA13 | 20 | SWDIO |
| SWD clock / BOOT0 | PA14 | 21 | SWCLK |
| RS-485 driver enable |  PB3 | 23 | USART1_DE |
| RGB channel 1 |  PB4 | 24 | TIM3_CH1 |
| RGB channel 2 |  PB5 | 25 | TIM3_CH2 |
| RS-485 transmit |  PB6 | 26 | USART1_TX |
| RS-485 receive |  PB7 | 27 | USART1_RX |
| Reset | NRST | 5 | NRST |

The physical RGB colours depend on the final cable wiring. Firmware should name the outputs by physical channel until the harness is fixed.

## Daisy-chain connector

The final PCB uses two identical 10-pin JST GH connectors:

- J2 IN
- J3 OUT

They are connected pin for pin.

| Pin | Signal  |
| --: | --- |
| 1 | RS485_P |
| 2 | RS485_N |
| 3 | SYNC_P  |
| 4 | SYNC_N  |
| 5 | 3V3 |
| 6 | GND |
| 7 | VLOAD |
| 8 | GND |
| 9 | VLOAD |
|  10 | GND |

Pins 7 and 9 are the same VLOAD net. Pins 6, 8, and 10 join the same PCB ground plane. Only the two physical ends of each differential bus are terminated.

The PCB contains optional 120 ohm termination resistors controlled by solder jumpers:

- JP1 enables 120 ohms across RS485_P and RS485_N
- JP2 enables 120 ohms across SYNC_P and SYNC_N

Leave both jumpers open on intermediate reward ports. Close them only when this PCB is the physical end of the corresponding bus. If a terminated end-of-line plug is used instead, leave the PCB jumpers open.

## RS-485 firmware

Initial configuration:

- USART1
- 500000 baud
- 8 data bits
- No parity
- 1 stop bit
- Half duplex
- Hardware driver enable output on PB3
- Hub master polling
- Reward ports transmit only when addressed

PB3 must default low so the reward port cannot drive the bus while resetting.

## SYNC capture

PA0 is configured as TIM2_CH1 input capture.

Recommended timer configuration:

- TIM2 timer clock: 64 MHz
- Prescaler: 63
- Counter rate: 1 MHz
- Counter period: 0xFFFFFFFF
- Counter mode: up
- CH1 capture: rising edge
- CH2 capture: rising edge

## Omron EE-SX1140 light gate

The light gate is an Omron EE-SX1140 slotted optical switch with:

- IR LED emitter
- Phototransistor detector
- 14 mm slot

Final connector wiring:

| J4 pin | Signal |
| -----: | --- |
| 1 | Phototransistor collector / BEAM_SENSE |
| 2 | Phototransistor emitter / GND |
| 3 | IR LED cathode / switched by MOSFET |
| 4 | IR LED anode / supplied through 100 ohms |

Detector circuit:

```text
    3V3
      |
     10k
      |
      +------ BEAM_SENSE ------ PA6 / ADC_IN6
      |
      +------ 1k ------ PA1 / TIM2_CH2
      |
     470pF
      |
     GND

    phototransistor collector -> BEAM_SENSE
    phototransistor emitter   -> GND
```

Signal behaviour:

- Clear slot: phototransistor conducts and BEAM_SENSE is low
- Blocked slot: phototransistor stops conducting and BEAM_SENSE rises
- TIM2_CH2 rising capture therefore records beam interruption

No external comparator is used. PA6 measures BEAM_SENSE with the ADC for setup and diagnostics. It must remain configured as an analogue input. PA1 must be configured as TIM2_CH2 alternate-function input. At startup, record the ADC level with the slot clear and blocked. Generate a sensor fault when the two states do not provide a safe digital margin.

### IR emitter control

PA3 controls the low-side IR emitter MOSFET.

At startup:

1. Keep the emitter disabled
2. Measure the dark detector level
3. Enable the emitter
4. Measure the clear-slot level
5. Verify that the expected transition occurred
6. Report a sensor fault when the test fails

The emitter may remain enabled during an active trial.

## RGB output

TIM3 produces three independent PWM outputs:

- PB4 / TIM3_CH1
- PB5 / TIM3_CH2
- PB0 / TIM3_CH3

Initial PWM frequency:

```text
2000 Hz
```

The remote common-anode RGB LED connects through J1:

- J1 pin 4: common anode to VLOAD
- J1 pins 1 to 3: LED cathode channels through 330 ohm resistors and low-side MOSFETs

Firmware must guarantee that all RGB channels are off during reset and before configuration is received.

Commands should support:

- RGB channel values
- Scheduled start timestamp
- Scheduled stop timestamp
- Command ID
- Session ID

## Audio

PA4 / DAC1_OUT1 generates the audio waveform. The final PCB uses a PAM8302A mono Class-D amplifier. The prototype may use a different analogue-input Class-D breakout while validating the DAC, waveform generation, speaker, and enclosure.

Recommended initial implementation:

- TIM6 triggers DAC1
- DAC1 uses DMA
- Sample rate: 96000 samples per second
- Double-buffered waveform generation
- PRNG noise source
- Configurable digital band-pass filter
- Configurable amplitude
- 5 to 10 ms onset and offset ramps

Initial test band:

```text
8000 Hz to 16000 Hz
```

This range is provisional. The actual usable range and level must be measured with the final speaker and enclosure at the animal position. PA2 controls amplifier shutdown. The speaker connects to J6 between amplifier OUT+ and OUT-. Neither speaker wire is ground.

## Solenoid valve

Valve:

```text
Lee Company LHDB0342115H
```

Driver:

```text
Texas Instruments DRV8837
```

Connections:

- DRV8837 VM to VLOAD
- DRV8837 VCC to 3V3
- DRV8837 nSLEEP to 3V3
- DRV8837 IN1 to PA8 / TIM1_CH1
- DRV8837 IN2 to GND
- DRV8837 OUT1 to J7 pin 1 / valve terminal 1
- DRV8837 OUT2 to J7 pin 2 / valve terminal 2
- DRV8837 GND and exposed pad to common ground
- 10 kOhm pull-down from IN1 to GND

The valve is driven between OUT1 and OUT2. It is not connected between one output and ground. With IN2 held low, IN1 high drives the valve and IN1 low places both outputs in the high-impedance coast state.

Place the 100 nF, 10 uF, and 470 uF bulk capacitors directly across VLOAD and ground near the DRV8837.

Initial valve PWM:

```text
25000 Hz
```

Initial drive sequence:

1. Apply spike PWM on IN1
2. Maintain the spike for approximately 10 to 15 ms
3. Change to hold PWM
4. Hold for the commanded reward duration
5. Set IN1 low
6. Record actual valve-off time

The Lee valve specifies approximately:

- 3.3 V actuation spike
- 2.0 V hold voltage
- 310 mW hold power

Initial duty profiles must be calibrated with the actual supply and valve.

Firmware must include:

- Absolute maximum valve-on timeout
- Valve off during reset
- Valve off on watchdog reset
- Valve off after communication or session fault
- Rejection of overlapping valve commands
- Minimum interval between valve activations
- Logged requested and actual valve times

## Clock and startup configuration

Use:

- Internal HSI16 oscillator
- PLL system clock at 64 MHz
- No external crystal
- No external TIMEBASE
- Brownout reset enabled
- Independent watchdog enabled
- SWD enabled on PA13 and PA14

Startup order:

1. Force valve, RGB, IR, and amplifier outputs into safe states
2. Initialize clocks
3. Initialize TIM2 and its overflow extension
4. Initialize event buffers
5. Initialize ADC and perform light-gate self-test
6. Initialize USART1 and RS-485 driver enable
7. Wait for hub discovery and session configuration
8. Accept commands only after synchronization is valid

## Prototype bring-up order

Bring up one subsystem at a time:

1. Nucleo serial logging
2. TIM2 free-running 1 MHz timer
3. Single-ended test pulse into PA0
4. Differential SYNC through two RS-485 breakouts
5. EE-SX1140 capture and ADC measurement
6. RGB PWM
7. DAC waveform generation
8. Audio amplifier and speaker
9. DRV8837 without valve attached
10. DRV8837 with valve and current-limited VLOAD supply
11. RS-485 protocol
12. Full clock translation and event logging

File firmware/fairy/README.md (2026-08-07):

# Fairy firmware

Fairy runs on STM32G071. It supports the NUCLEO G071RB prototype and the planned STM32G071GBU6 board through one board profile file.

## Responsibilities

- Read the 96 bit STM32 factory UUID
- Join the RS485 bus through Magellan
- Capture 4 Hz SYNC on TIM2 channel 1
- Capture light gate interruption on TIM2 channel 2
- Debounce light gate edges for 100 ms
- Buffer Fairy v3 records until Korora acknowledges them
- Drive RGB at 2 kHz
- Generate tone or band limited white noise with DAC DMA
- Apply a 10 ms audio onset and offset ramp
- Drive the valve at 25 kHz with spike and hold duty
- Enforce valve safety limits
- Run an independent watchdog
- Perform a light gate startup self test
- Stop the local session after two seconds without Korora contact

## Select a profile

`FAIRY_BOARD_PROFILE=1` selects the Nucleo prototype.

`FAIRY_BOARD_PROFILE=2` selects the final package pin plan.

All pin decisions are in:

```text
include/board_profile.hpp
src/board_profile.cpp
```

This is the intended place to change a prototype pin.

## Prototype pins

The user supplied PC4 and PC5 choice is used for USART1. The automatic
direction Grove module means no direction pin is driven.

| Function | STM32 pin | Peripheral |
| --- | --- | --- |
| SYNC capture | PA0 | TIM2 channel 1 |
| Light gate capture | PA1 | TIM2 channel 2 |
| Audio DAC | PA4 | DAC1 output 1  |
| Light gate ADC | PA6 | ADC input 6 |
| Valve PWM | PA8 | TIM1 channel 1 |
| RS485 TX | PC4 | USART1 TX |
| RS485 RX | PC5 | USART1 RX |
| RGB blue | PB0 | TIM3 channel 3 |
| RGB red | PB4 | TIM3 channel 1 |
| RGB green | PB5 | TIM3 channel 2 |
| Amplifier shutdown | PC0 | GPIO |
| IR emitter enable  | PC1 | GPIO |
| Human debug UART | PA2 and PA3 | USART2 |

## Final PCB pins

| Function | STM32 pin | Peripheral |
| --- | --- | --- |
| SYNC capture | PA0 | TIM2 channel 1 |
| Light gate capture | PA1 | TIM2 channel 2 |
| Amplifier shutdown | PA2 | GPIO |
| IR emitter enable  | PA3 | GPIO |
| Audio DAC | PA4 | DAC1 output 1  |
| Light gate ADC | PA6 | ADC input 6 |
| RGB blue | PB0 | TIM3 channel 3 |
| Valve PWM | PA8 | TIM1 channel 1 |
| RS485 direction | PB3 | GPIO |
| RGB red | PB4 | TIM3 channel 1 |
| RGB green | PB5 | TIM3 channel 2 |
| RS485 TX | PB6 | USART1 TX |
| RS485 RX | PB7 | USART1 RX |

The final profile disables the human debug UART.

## Build and upload

```bash
pio run -d fairy -e nucleo_g071rb_auto_rs485
pio run -d fairy -e nucleo_g071rb_auto_rs485 -t upload
```

Build the final pin profile:

```bash
pio run -d fairy -e final_pcb_g071gb
```

Flash all stm32 boards:

```bash
python scripts/flash_all.py --jobs 1
```

## Timing

The HSI16 and PLL create a 64 MHz system clock. TIM2 prescaler 3 creates the required 16 MHz free running counter. A 32 bit overflow extension produces 64 bit timestamps.

SYNC captures the falling edge because Korora generates an active low pulse. Light gate captures the rising edge for beam interruption.

## Light gate

Startup:

1. Keep the IR emitter off
2. Measure the pulled high dark value
3. Enable the emitter
4. Measure the clear slot value
5. Require at least 400 ADC counts of separation
6. Emit a critical fault when the test fails

The emitter returns to off after the startup test and is enabled when a session starts. A 100 ms digital debounce suppresses small tremor edges while keeping the expected mouse snout event rate.

## Audio

Audio mode 1 is a tone. Audio mode 2 is band limited white noise. Initial values in Adelie are 8000 Hz to 16000 Hz and amplitude 512.

The timer period gives approximately 95952 samples per second from the 64 MHz clock. DMA uses a 256 sample circular buffer with half buffer callbacks.

## Valve

Initial 5 V values are:

| Setting | Value |
| --- | ---: |
| Spike duration | 12000 us |
| Spike duty | 660 per mille |
| Hold duty | 400 per mille |
| Hard maximum | 250000 us |
| Minimum interval | 250000 us |

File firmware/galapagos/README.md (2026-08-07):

# Galapagos firmware

Galapagos runs on the nRF54L15 DK with Zephyr. It creates hardware timed TTL pulses and reports its local measurements to Korora.

## Responsibilities

- Advertise one Galapagos BLE service
- Report selected BLE connection anchor observations
- Accept only Adelie v2 commands from Korora
- Schedule TTL set and clear events with GRTC
- Drive the TTL pin through DPPI and GPIOTE
- Queue up to eight future TTL pulses
- Capture a general digital input with GRTC
- Publish Fairy v3 records
- Force TTL low on disconnect or session stop

## Pin assignment

The overlay is `boards/nrf54l15dk_nrf54l15_cpuapp.overlay`.

| Function | Pin |
| --- | ----- |
| General event input | P1.11 |
| TTL output | P1.12 |

For the current timing test, connect P1.12 to Korora P0.02 and connect the grounds. The output can later connect to the real TTL input without changing the application protocols.

## Files

| File | Purpose |
| --- | --- |
| `main.cpp` | Startup only |
| `hardware.cpp` | GRTC, DPPI, capture, and TTL output |
| `application.cpp` | Sessions and Adelie command execution |
| `record_stream.cpp` | Serialized Fairy and response notifications |
| `ble_service.cpp` | GATT service and BLE anchor reports |
| `debug_log.cpp` | Isolated human serial text |

## Build

```bash
west build -p always -b nrf54l15dk/nrf54l15/cpuapp galapagos
west flash
```

The build requires an nRF Connect SDK version that provides the SoftDevice Controller anchor report extension and the nRF54L15 GRTC driver.

## TTL rules

- Target time must be aligned to a 1 us GRTC tick
- Target must be at least 50 ms in the future
- Width must be between 1 us and 2000000 us
- Pulses must arrive in increasing target order
- One active pulse and eight queued pulses are supported
- Stop session disables compare events and disconnects TTL DPPI routes

Galapagos emits `TTL generated` from the compare callback. The record contains sequence, requested local time, actual local compare time, and width.

## Debug output

Set `FAIRY_ENABLE_DEBUG_STREAM=0` as a C++ build definition for a custom PCB. Debug output is not an application link and is never parsed. Merge `debug_off.conf` in a custom build so Zephyr does not claim a console:

```bash
west build -p always -b YOUR_BOARD galapagos -- \
  -DFAIRY_ENABLE_DEBUG_STREAM=0 -DEXTRA_CONF_FILE=debug_off.conf
```

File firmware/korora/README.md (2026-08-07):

# Korora firmware

Korora runs on the nRF52840 DK with Zephyr. It is the system time authority, BLE gateway, RS485 master, Fairy inventory owner, and experiment scheduler.

## Responsibilities

- Generate the 4 Hz SYNC pulse from a 16 MHz hardware timer
- Poll up to `FAIRY_MAX_BOARDS` Fairy boards
- Run Magellan discovery and address assignment
- Fit one clock model for every live Fairy
- Connect to exactly one Galapagos over BLE
- Fit the Galapagos BLE anchor clock model
- Advertise the Adelie BLE service
- Route every command through the Adelie protocol
- Route every record through the Fairy protocol
- Serialize all RS485 and BLE writes
- Prioritize Galapagos timing commands and Adelie responses over telemetry
- Schedule TTL trains and capture the prototype loopback
- Stop the active session when Adelie disconnects

## Files

| File | Purpose |
| --- | --- |
| `main.cpp` | Startup only |
| `timebase.cpp` | TIMER2 SYNC and event capture, TIMER3 TTL capture |
| `controller_clock.cpp`  | BLE controller clock bridge |
| `rs485_bus.cpp` | COBS, polling, retries, and bus mutex |
| `fairy_manager.cpp` | Discovery, inventory, polling, and Fairy clock models |
| `ble_gateway.cpp` | Adelie server and Galapagos client |
| `galapagos_manager.cpp` | BLE anchor pairing and record conversion |
| `experiment.cpp` | Session records, TTL train, loopback, and sync test |
| `control.cpp` | Adelie command routing and local operations |
| `debug_log.cpp` | Isolated human serial text |

## Pin assignment

The overlay is `boards/nrf52840dk_nrf52840.overlay`.

| Function | Pin |
| --- | ----- |
| SYNC output | P1.10 |
| General event input | P1.11 |
| Galapagos TTL loopback input | P0.02 |
| RS485 UART TX | P0.27 |
| RS485 UART RX | P0.26 |

The prototype RS485 modules provide automatic direction control. No direction GPIO is used.

## Build

From a Zephyr or nRF Connect SDK workspace:

```bash
west build -p always -b nrf52840dk/nrf52840 korora
west flash
```

To build the two Fairy prototype capacity:

```bash
west build -p always -b nrf52840dk/nrf52840 korora -- \
  -DFAIRY_MAX_BOARDS=2
```

The default remains six boards.

## Configuration

`prj.conf` enables:

- C++17
- BLE central and peripheral roles
- Two BLE connections
- 247 byte L2CAP MTU
- Nordic TIMER, RTC, GPIOTE, and GPPI drivers
- Crystal low frequency clock

To disable all human serial output add this build definition:

```text
FAIRY_ENABLE_DEBUG_STREAM=0
```

For a custom board, also merge `debug_off.conf` so Zephyr does not claim a console:

```bash
west build -p always -b YOUR_BOARD korora -- \
  -DFAIRY_ENABLE_DEBUG_STREAM=0 -DEXTRA_CONF_FILE=debug_off.conf
```

`CONFIG_SERIAL` remains enabled because Korora uses UART1 for RS485.

Do not send debug text through the RS485 UART.

## Runtime states

Korora can discover, synchronize, and report health before Adelie connects. It has no experiment storage.

A normal run starts only after:

- Every live UUID is assigned
- Every Fairy clock model is valid
- Galapagos is connected
- The Galapagos clock model is valid

If a Fairy stops responding for three seconds, it leaves the live inventory. If it returns, Magellan restores its address. A changed UUID requires a new Adelie configuration.

## RS485 timing

Assigned Fairies are polled every 10 ms. Poll responses allow 12 ms. This covers a maximum Fairy record at 460800 baud. Failed transactions receive one retry. Absent nodes are probed at a slower rate so one missing board does not occupy the bus.

The bus mutex remains held across the poll request, response, and record acknowledgement. A command or discovery round cannot enter that transaction.

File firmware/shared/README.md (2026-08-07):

# Shared C++ library

The shared folder contains code used by Korora, Galapagos, and Fairy. It has no heap requirement and does not depend on Zephyr or STM32 HAL.

## Modules

| Module | Purpose |
| --- | --- |
| `system_config.hpp` | Maximum boards, addresses, rates, and debug switch |
| `bytes.hpp` | Checked little endian readers and writers |
| `crc16.hpp` | CRC16 CCITT |
| `static_queue.hpp` | Fixed capacity queue |
| `transport.hpp` | Transport framing, COBS, and reassembly |
| `tlv.hpp` | Flexible typed fields |
| `fairy_protocol.hpp` | Fairy v3 record codec |
| `adelie_protocol.hpp` | Adelie v2 command codec |
| `magellan_protocol.hpp` | Discovery and assignment codec |
| `clock_model.hpp` | Fixed window affine clock model |

## Configuration

The main build values are at the top of `include/fairy_shared/system_config.hpp`.

```cpp
#define FAIRY_MAX_BOARDS 6
#define FAIRY_ENABLE_DEBUG_STREAM 1
```

They can also be supplied as compiler definitions. The wire format allows at most 14 Fairies in one inventory response. This project defaults to six.

## PlatformIO

`library.json` lets the Fairy project include this folder through `lib_deps`.

## Host tests

The test builds the protocol code with the host C++ compiler and checks:

- Transport encode and decode
- COBS framing
- Fragment reassembly
- Fairy record round trip
- Adelie command round trip
- Magellan UUID assignment
- Clock model fit and inverse conversion

Run:

```bash
bash tests/run_host_tests.sh
```

The test uses C++17 with warnings enabled.

## Extension rules

- Add application fields as new TLV tags
- Never reuse an existing numeric meaning
- Keep unknown field handling permissive
- Increase an application protocol version for an incompatible change
- Increase Transport only when frame interpretation changes
- Keep all fixed wire structs independent of compiler packing

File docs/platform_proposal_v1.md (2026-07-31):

# Overall architecture - Platform proposal v1

- A moving **nRF52840 hub** owns the platform time base, trial state, event collection, buffering, and direct BLE communication with the main computer.
- Each reward port contains an **STM32G071-class MCU** that counts the hub-distributed 1 MHz TIMEBASE, captures inputs in hardware, and executes pre-armed outputs using timer compare.
- Reward ports communicate with the hub over a half-duplex **RS-485 linear trunk**.

```text
                    CENTRAL HUB
 ┌────────────────────────────────────────────────────┐
 │ nRF52840 + Zephyr                                  │
 │                                                    │
 │ Trial state machine        BLE / USB to host       │
 │ Command scheduler          Raw logging + buffering │
 │                                                    │
 │ Shared oscillator ── divider ── timing counter     │
 │                          │                         │
 │                          ├── differential TIMEBASE │
 │                          └── differential SYNC     │
 │                                                    │
 │                                                    │
 │ RS-485 master ─────────────── data bus             │
 │ Battery protection/charger + regulated rails       │
 └────────────────────────────────────────────────────┘
              │
              │ Power, RS-485, TIMEBASE, SYNC
              │
 ┌───────────────────────────────────────────────────────┐
 │ REWARD-PORT MCU — STM32G071-class                     │
 │                                                       │
 │ Shared-time timer                                     │
 │   ├── beam-break hardware capture                     │
 │   ├── scheduled RGB output compare                    │
 │   ├── scheduled audio start                           │
 │   └── scheduled valve pulse                           │
 │                                                       │
 │ Event ring buffer and sequence IDs                    │
 │ RGB driver | audio driver | solenoid MOSFET | spares  │
 └───────────────────────────────────────────────────────┘
```

## Decisions TLDR:

- **Moving hub:** nRF52840 running Zephyr / nRF Connect SDK
- **Reward-port MCU:** Prefer STM32G071KB in a 32-pin package
- **Platform timing:** One 1 MHz differential TIMEBASE plus a separate differential SYNC line.
- **Reward-port timestamping:** 32-bit hardware counter extended to 64 bits in software.
- **Internal data bus:** Half-duplex UART over RS-485, hub-master polled, CRC protected, sequence numbered
- **Host data path:** Moving hub communicates event records directly to the computer over BLE
- **Power:** Regulated 3.3 V logic rail and a separately controlled valve/audio power domain
- **Control:** Stimuli and rewards are scheduled through hardware timer compare or pre armed local rules
- **Logging:** Log requested and actual action timestamps, command IDs, event sequence IDs, clock health records, and synchronization quality

For example:

```text
REWARD-PORT 3:
  cue_start_tick = 18,500,000
  cue_stop_tick  = 18,750,000
  on_valid_beam_break:
    valve_on after 500 us
    valve_off after 25 ms
```

Hub delivers this command structure early, leaving the reward-port MCU with timing execution.

---

# 1. Platform timing architecture

## Shared 1 MHz TIMEBASE

A stable oscillator or TCXO is divided to generate a 1 MHz differential TIMEBASE. Each reward-port MCU:

- runs its processor from an internal or local processor clock
- configures a hardware timer to count external TIMEBASE edges
- obtains one timing tick per microsecond
- does not count the timebase in an interrupt
- does not reconstruct time from RS-485 messages

Advantages:

- all reward ports share frequency directly
- processor startup and PLL behaviour do not affect event time
- distribution frequency is much lower than a 16–32 MHz processor clock
- scheduled timestamps are directly comparable between modules
- drift between reward ports is removed while the distributed clock remains healthy

## Separate SYNC line

A common timebase establishes a common rate but not a common counter value. Modules may start counting at different times. The hub therefore distributes a separate differential SYNC signal. Example semantics:

- **Session-start SYNC:** establishes the initial epoch and module offset.
- **Periodic SYNC:** captured by every module for clock-health verification.
- **Periodic SYNC should not blindly reset counters.** It should record a capture and check whether the expected offset has changed.

For module \(i\):
$H = L_i + b_i$

where:

- \(H\) is platform time
- \(L_i\) is the reward-port local external-clock counter
- \(b_i\) is the module offset measured from SYNC

Because frequency is shared, \(b_i\) should remain constant. A change indicates a fault such as:

- a missed or additional TIMEBASE edge
- a corrupted SYNC edge
- timer reconfiguration
- module reset
- cable or receiver fault

SYNC frequency is to be determined, needs can be estimated with experimental data.

## Clock-fault behaviour

Each reward port should detect:

- TIMEBASE missing
- unexpected offset change
- SYNC timeout
- timer overflow extension inconsistency
- reset during an active session

On clock failure, the reward port should:

1. force valve outputs off
2. cancel or disarm future time critical outputs
3. preserve existing event records where possible
4. create a `CLOCK_FAULT` event
5. report fault status when communication is available
6. require an explicit recovery or reinitialization sequence

## 64-bit timestamp construction

At 1 MHz, a 32-bit counter wraps after:
$2^{32}\ \mu s \approx 71.58\ \text{minutes}$

A software overflow word extends it to 64 bits:

```c
uint64_t timestamp =
    ((uint64_t)overflow_count << 32) |
    hardware_counter;
```

A 64-bit microsecond counter lasts approximately 584,000 years which should suffice.

The implementation must handle capture close to overflow without producing an incorrect high word. Exact method is to be decided on firmware.

---

# 2. Internal cable communication

## Why not I2C

I2C is not preferred for the removable multidrop platform trunk because of:

- sensitivity to bus capacitance and connector changes
- weaker noise margin near solenoid, PWM, audio, and power wiring
- awkward expansion and hot plug behaviour
- addressing limitations
- shared clock stretching and stuck bus failure modes
- reduced fault isolation

I2C remains appropriate for short, local board-level communication.

## RS-485 baseline

Using half-duplex RS-485 with the hub as the only bus master seems to be a good option.

```text
Bit rate:          500 kbit/s initial; 1 Mbit/s after validation
Electrical form:   half-duplex differential
Topology:          electrically linear daisy-chain trunk
Termination:       at the two electrical ends only
Protocol:          hub-master polling
Integrity:         CRC-16
Addressing:        assigned short address plus immutable factory UID
Recovery:          mandatory timeout and bus reset strategy
```

## Frame structure

Proposed/example logical frame:

```c
struct bus_frame_header {
    uint8_t  protocol_id;
    uint8_t  message_type;
    uint8_t  source_address;
    uint8_t  destination_address;
    uint16_t payload_length;
    uint16_t flags;
    uint32_t frame_sequence;
    uint32_t session_id;
};
```

Followed by payload and CRC. The protocol should define:

- byte order
- framing/escaping
- maximum payload
- request response timeout
- retry policy
- duplicate command behaviour
- module reset detection

## Discovery and commissioning

Each MCU exposes its factory UID. A practical discovery process:

1. hub enters commissioning mode
2. uncommissioned modules respond in pseudorandom or UID derived slots
3. hub resolves collisions through repeated rounds
4. hub assigns a short bus address
5. module identity and physical port position are recorded
6. assignment is stored with a configuration generation number

This needs to happen only when there isn't a mapping already present.

## Polling policy

Modules respond only when addressed. The hub polls:

- event count or status first
- event records in bounded batches
- health counters at a lower rate
- configuration acknowledgements after changes

---

# 3. Reward-port MCU selection and resource plan

## Selected family

Preferred baseline: **STM32G071KB** in a 32-pin package. Reasons:

- one 32-bit general purpose timer
- additional timers for capture, compare, PWM, and audio
- DMA
- multiple USARTs
- hardware CRC
- watchdogs
- 96 bit unique ID;
- more RAM and timer flexibility than the minimal G031 option.

## Pin budget

| Function | Approximate GPIO count |
| --- | ---: |
| RS-485 TX, RX, driver-enable | 3 |
| TIMEBASE differential receiver output | 1 |
| SYNC differential receiver output | 1 |
| Beam-break capture | 1 |
| RGB PWM | 3 |
| Audio PWM/data | 1 |
| Solenoid command and optional sense | 2 |
| SWD debug | 2 |
| Address/configuration/service | 1–3 |
| Status/test output | 1 |
| Optional current/flow/temperature inputs | 1–3 |

## Timer allocation - provisional

A candidate allocation is:

```text
TIM2  — 32-bit external TIMEBASE counter
TIM3  — RGB PWM channels
TIM1  — beam-break capture and/or precisely related output actions
TIM14/15/16/17 — valve, audio envelope, service timing as available
DMA   — audio waveform and event movement where useful
```

---

# 4. Peripheral event engine

## Beam-break input capture

```text
Emitter / detector
      ↓
analogue conditioning
      ↓
comparator with hysteresis
      ↓
timer input capture
      ↓
capture register or DMA
      ↓
event ring buffer
```

Hardware capture latches the timestamp at the electrical edge. Interrupt latency may delay processing but does not alter the captured value. Debouncing could use comparator hysteresis.

## Event structure

Example event record:

```c
struct port_event {
    uint64_t actual_timestamp_ticks;
    uint64_t scheduled_timestamp_ticks;
    uint32_t event_sequence;
    uint32_t command_id;
    uint32_t session_id;
    uint16_t event_type;
    uint16_t flags;
    uint32_t data;
};
```

Event types examples:

```text
BEAM_ENTER
BEAM_EXIT
CUE_ON
CUE_OFF
AUDIO_ON
AUDIO_OFF
VALVE_ON
VALVE_OFF
COMMAND_RECEIVED
COMMAND_ARMED
SYNC_CAPTURE
```

All events get captured, allows for full reconstruction of events

## Output scheduling

Use timer output compare instead of firmware delays for:

- RGB onset and offset
- audio envelope or waveform start
- valve gate on and off
- status test pulses

Command acceptance requires sufficient lead time, both for practical implementation reasons but also validation reasons.

## Conditional rules

Local rules reduce latency:

```text
IF response_window_active
AND module_is_correct_target
AND beam_event_is_valid
THEN:
    valve_on  at captured_tick + configured_delay
    valve_off at captured_tick + configured_delay + configured_duration
```

Rules should be:

- configured by the hub
- associated with a configuration generation
- bounded in capability
- validated before arming
- disabled on clock or safety fault
- logged when triggered

Exact implementation is purely on firmware level leaving it up to decision as of now.

## Command idempotency

Every command carries a unique `command_id`. Receiving the same command twice must not schedule it twice. A module should return a double command error for a duplicate command.

---

# 5. LED subsystem

Each reward port provides independently controlled RGB output.

```text
MCU timer PWM
    → current-limited LED channels
```

Requirements:

- defined off-state during reset
- configurable intensity and duration
- timer-controlled start and stop
- low-noise current paths
- no high-current LED return through sensitive detector ground
- calibrated optical onset where scientific timing requires it

---

# 6. Audio subsystem

## 8.1 Simple tones and beeps

```text
timer PWM
    → amplifier or piezo driver
    → transducer
```

## 8.2 Complex auditory stimuli

For clicks, sweeps, noise bursts, or calibrated waveforms:

```text
waveform buffer
    → timer-triggered DMA
    → high-rate PWM or DAC/codec
    → reconstruction/filter/amplifier
    → speaker
```

The MCU should trigger playback from a timer event. Interrupt driven sample generation is not acceptable for calibrated timing.

The final design depends on:

- required frequency range
- sound pressure level
- waveform complexity
- acceptable distortion
- memory requirements
- speaker and enclosure geometry

---

# 7. Solenoid and reward power

## Driver requirements

Each valve driver should include:

- logic-level MOSFET
- gate pulldown
- defined off state during reset
- flyback suppression
- local bulk capacitance
- short high current loop
- independent maximum on time protection
- watchdog behaviour that forces valve off

## Power regulation

A battery is not a stable valve rail. Valve force and timing may vary with state of charge if connected directly. Proposed architecture:

```text
Battery / protected supply
    ├── regulated 3.3 V logic domain
    └── regulated or controlled valve/audio domain
```

The design must specify:

- valve voltage and peak current
- simultaneous valve/audio activation assumptions
- cable voltage drop
- regulator transient response
- minimum battery voltage
- local capacitance
- permitted rail droop

---

# 8. Cable and physical topology

## Signal pairs

Minimum data/timing pairs:

```text
Pair 1: RS-485 A / B
Pair 2: TIMEBASE+ / TIMEBASE-
Pair 3: SYNC+ / SYNC-
```

### five pair arrangement (preferred)

```text
Pair 4: LOGIC_POWER / LOGIC_RETURN
Pair 5: VALVE_POWER / VALVE_RETURN
```

### Four pair arrangement

```text
Pair 4: distributed higher-voltage POWER / GND
```

## Module protection and test access

Each module should include:

- local decoupling
- local bulk capacitance near the valve driver
- ESD/TVS protection selected for the relevant pair
- receiver input protection
- test points for TIMEBASE, SYNC, RS-485, beam input, valve gate, logic rail, and valve rail
- controlled logic and valve return routing

---

# 11. Hub design

## Hub responsibilities

The moving nRF52840 hub owns:

- platform time authority
- trial and protocol configuration
- future timestamp command scheduling
- reward port discovery and health polling
- event collection
- sequence gap detection
- event buffering
- direct BLE telemetry to the computer
- power and battery monitoring
- fault reporting

## Buffering

BLE delivery is not real-time storage. The hub should buffer events until acknowledged or safely written to the host.

Buffer design should define:

- expected average and burst event rates
- record size
- minimum disconnected duration
- overwrite policy
- overflow behaviour

The platform should preserve timing correctness during temporary BLE interruption.

## Position tracking

?

# 10. Validation plan

## EMC validation

Test with (if tools available):

- maximum valve activity
- maximum LED PWM
- maximum audio load
- both BLE connections active
- ephys acquisition active
- complete final harness and enclosure

Record noise spectra and artefacts in the actual acquisition chain.

## Endurance validation

Running longer than the target session duration with:

- maximum expected IMU rate
- high reward port event load
- delayed or interrupted host BLE
- active timing bridge
- battery at end of discharge conditions
- worst case environmental temperature

Monitor:

- battery voltage
- regulator temperature
- buffer occupancy
- dropped frames
- BLE reconnects
- module resets
- valve rail droop

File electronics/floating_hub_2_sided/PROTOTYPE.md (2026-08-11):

# Korora prototype

Prototype wiring for the Korora hub using the hardware currently on hand:

- Nordic nRF52840 DK
- ST STEVAL-MKI240KA / LSM6DSV32X 6-axis IMU
- MEMSIC MMC5983MA-B / MMC5983MA 3-axis magnetometer
- Existing Fairy communication hardware and firmware

Both motion sensors connect directly to the nRF52840 over one shared I2C bus.

The nPM power system is not part of this prototype wiring revision. During sensor bring-up, the nRF52840 DK supplies the sensor boards from its 3.3 V rail.

## Prototype architecture

```text
                              existing Fairy hardware
                                      |
                                      |
                         UART / SYNC / EVENT / TTL
                                      |
                                      v
                         +-------------------------+
                         |      nRF52840 DK        |
                         |                         |
                         | Fairy UART              |
                         | TX  P0.27               |
                         | RX  P0.26               |
                         |                         |
                         | Korora sensor I2C       |
                         | SDA P0.30 / A4          |
                         | SCL P0.31 / A5          |
                         +-----+--------------+----+
                               |              |
                         shared I2C      shared I2C
                               |              |
                               v              v
                    +----------------+   +----------------+
                    | STEVAL-        |   | MMC5983MA-B    |
                    | MKI240KA       |   |                |
                    | LSM6DSV32X     |   | MMC5983MA      |
                    | accel + gyro   |   | magnetometer   |
                    | addr 0x6A      |   | addr 0x30      |
                    +----------------+   +----------------+

                         optional interrupt GPIOs

                    IMU INT1 -------> P0.28 / A2
                    MAG INT  -------> P0.29 / A3
```

## nRF52840 DK sensor pin assignment

| Function | nRF GPIO | DK header name | Use |
| --- | --- | --- | --- |
| I2C SDA | P0.30 | A4 | shared sensor SDA |
| I2C SCL | P0.31 | A5 | shared sensor SCL |
| IMU INT1 | P0.28 | A2 | optional/recommended data-ready interrupt |
| MAG INT | P0.29 | A3 | optional/recommended data-ready interrupt |
| Sensor supply | 3V3 | 3.3 V power header | both eval boards |
| Sensor ground | GND | GND | common ground |

A2 and A3 are only used for interrupt outputs. All sensor register communication remains I2C.

## Shared I2C bus

Both sensor boards are connected in parallel:

```text
nRF P0.30 / A4 / SDA
        |
        +---------- STEVAL-MKI240KA SDA
        |
        +---------- MMC5983MA-B SDA

nRF P0.31 / A5 / SCL
        |
        +---------- STEVAL-MKI240KA SCL
        |
        +---------- MMC5983MA-B SCL
```

Common supply:

```text
nRF DK 3V3
   |
   +---------- STEVAL-MKI240KA VDD
   +---------- STEVAL-MKI240KA VDDIO
   +---------- MMC5983MA-B VDD

nRF DK GND
   |
   +---------- STEVAL-MKI240KA GND
   +---------- MMC5983MA-B GND
```

## STEVAL-MKI240KA

Sensor:

```text
LSM6DSV32X
3-axis accelerometer
3-axis gyroscope
```

For this prototype it is used only as a normal I2C peripheral.

Do not use the LSM6DSV32X sensor-hub pins to attach the magnetometer. The magnetometer is connected directly to the nRF52840 on the same I2C bus.

### I2C mode configuration

For I2C operation:

```text
CS       -> 3V3 / VDDIO
SDO/SA0  -> GND
```

With `SDO/SA0` low, the selected 7-bit address is:

```text
0x6A
```

The alternative address with `SDO/SA0` high is `0x6B`, but use `0x6A` for this prototype so the wiring and firmware are deterministic.

### STEVAL-MKI240KA wiring

Use the signal names printed on the board / DIL24 adapter.

| STEVAL-MKI240KA signal | Connect to nRF52840 DK  | Purpose |
| --- | --- | --- |
| VDD | 3V3 | sensor supply |
| VDDIO | 3V3 | digital I/O supply |
| GND | GND | common ground |
| SDA | A4 / P0.30 | shared I2C SDA |
| SCL | A5 / P0.31 | shared I2C SCL |
| CS | 3V3 | selects I2C interface |
| SDO/SA0 | GND | selects address 0x6A |
| INT1 | A2 / P0.28 | optional/recommended data-ready interrupt |
| INT2 | not connected initially | reserve for later use |
| SDx | not connected initially | sensor-hub / auxiliary function not used  |
| SCx | not connected initially | sensor-hub / auxiliary function not used  |
| OCS / OCS_Aux | not connected initially | auxiliary interface not used |
| SDO_Aux | not connected initially | auxiliary interface not used |

## MMC5983MA-B

Sensor:

```text
MMC5983MA
3-axis magnetometer
```

The MMC5983MA-B prototyping board exposes two four-pin headers.

### I2C mode configuration

For I2C operation, SPI chip select must be held high:

```text
P1-1 SPI_CS -> 3V3
```

The MMC5983MA uses the fixed 7-bit I2C address:

```text
0x30
```

This does not conflict with the IMU at `0x6A`.

### MMC5983MA-B wiring

| MMC5983MA-B pin | Signal  | Connect to nRF52840 DK |
| --- | --- | --- |
| P1-1 | SPI_CS  | 3V3 |
| P1-2 | NC | no connection |
| P1-3 | VDD | 3V3 |
| P1-4 | GND | GND |
| P2-1 | SPI_SDO | no connection |
| P2-2 | SDA | A4 / P0.30 |
| P2-3 | SCL | A5 / P0.31 |
| P2-4 | INT | A3 / P0.29 optional/recommended |

## Complete wiring table

| nRF52840 DK | nRF GPIO | STEVAL-MKI240KA | MMC5983MA-B |
| --- | --- | --- | --- |
| 3V3 | - | VDD | P1-3 VDD |
| 3V3 | - | VDDIO | P1-1 SPI_CS |
| GND | - | GND | P1-4 GND |
| A4 | P0.30 | SDA | P2-2 SDA |
| A5 | P0.31 | SCL | P2-3 SCL |
| A2 | P0.28 | INT1 | - |
| A3 | P0.29 | - | P2-4 INT |
| GND | - | SDO/SA0 | - |
| 3V3 | - | CS | - |

## Zephyr overlay

The existing Fairy overlay should be preserved.

Use the following merged overlay for the prototype:

```dts
#include <zephyr/dt-bindings/gpio/gpio.h>
#include <zephyr/dt-bindings/pinctrl/nrf-pinctrl.h>
#include <zephyr/dt-bindings/i2c/i2c.h>

/ {
    zephyr,user {
        /*
         * Existing Fairy signals.
         * Keep these assignments unchanged.
         */
        sync-gpios = <&gpio1 10 GPIO_ACTIVE_LOW>;
        event-gpios = <&gpio1 11 GPIO_ACTIVE_HIGH>;
        ttl-input-gpios = <&gpio0 2 GPIO_ACTIVE_HIGH>;

        /*
         * Korora sensor interrupt inputs.
         * Sensor register communication itself is entirely I2C.
         */
        imu-int-gpios = <&gpio0 28 GPIO_ACTIVE_HIGH>;
        mag-int-gpios = <&gpio0 29 GPIO_ACTIVE_HIGH>;
    };
};

&pinctrl {
    /*
     * Existing Fairy UART.
     */
    fairy_uart1_default: fairy_uart1_default {
        group1 {
            psels = <NRF_PSEL(UART_TX, 0, 27)>;
        };

        group2 {
            psels = <NRF_PSEL(UART_RX, 0, 26)>;
            bias-pull-up;
        };
    };

    fairy_uart1_sleep: fairy_uart1_sleep {
        group1 {
            psels = <NRF_PSEL(UART_TX, 0, 27)>,
                    <NRF_PSEL(UART_RX, 0, 26)>;
            low-power-enable;
        };
    };
};

&uart1 {
    compatible = "nordic,nrf-uarte";
    status = "okay";
    current-speed = <460800>;
    pinctrl-0 = <&fairy_uart1_default>;
    pinctrl-1 = <&fairy_uart1_sleep>;
    pinctrl-names = "default", "sleep";
};

/*
 * The DK normally maps i2c0 onto P0.26/P0.27.
 *
 * Fairy owns those pins, so i2c0 must be disabled when
 * CONFIG_I2C is enabled.
 */
&i2c0 {
    status = "disabled";
};

/*
 * The DK board definition says i2c1 and spi1 cannot be used
 * together. Korora uses this peripheral instance for I2C.
 */
&spi1 {
    status = "disabled";
};

/*
 * nRF52840 DK default i2c1 pinctrl:
 *
 * SDA = P0.30 = A4
 * SCL = P0.31 = A5
 */
&i2c1 {
    status = "okay";
    clock-frequency = <I2C_BITRATE_STANDARD>;
};

&timer2 {
    status = "okay";
};

&timer3 {
    status = "okay";
};

&rtc2 {
    status = "okay";
};
```

No sensor child nodes are required for the first electrical bring-up.

The first firmware test can talk to the devices through the normal Zephyr I2C API using their addresses directly:

```text
LSM6DSV32X = 0x6A
MMC5983MA  = 0x30
```

This avoids making the prototype depend on the exact sensor-driver support present in a particular Zephyr / nRF Connect SDK version.

Once the raw bus is proven, proper driver/devicetree integration can be added separately.

## Interrupt wiring

The sensors can initially be polled over I2C.

However, the recommended final prototype wiring includes:

```text
LSM6DSV32X INT1 -> P0.28 / A2
MMC5983MA INT    -> P0.29 / A3
```

This allows later firmware to timestamp data-ready events and avoids making the acquisition timing depend on a polling loop.

Do not enable GPIO interrupts until normal I2C reads are working.

### IMU interrupt

Use INT1 initially for accelerometer / gyroscope data-ready or FIFO watermark.

The exact routing is configured inside the LSM6DSV32X registers.

### Magnetometer interrupt

The MMC5983MA INT output can be used for measurement/data-ready operation when configured.

It is not required for the first I2C communication test.

## Sensor acquisition strategy

The first implementation should keep acquisition simple:

```text
nRF52840
   |
   +-- read LSM6DSV32X accel + gyro
   |
   +-- read MMC5983MA magnetometer
   |
   +-- timestamp data in Korora hub time
   |
   +-- fairy event generated
```

Do not use the LSM6DSV32X embedded sensor hub for the MMC5983MA in this prototype.

The nRF52840 should own both sensors directly.

## Magnetometer placement during prototype testing

Keep the MMC5983MA-B away from:

- speakers
- solenoids
- steel tools
- bench supply transformers
- large current loops
- the nRF DK USB cable if it carries significant nearby current
- magnets
- ferromagnetic breadboard hardware

For early software development it can sit on jumper wires away from the DK.

This will make calibration and heading tests much more meaningful.

## 9-DoF output goal

The combined prototype provides:

```text
LSM6DSV32X:
    acceleration X/Y/Z
    angular rate X/Y/Z

MMC5983MA:
    magnetic field X/Y/Z
```

giving nine measured axes.

Target application update rate:

```text
20-100 Hz
```

The sensors do not by themselves provide drift-free long-term XYZ position.

## Existing Fairy timing

The existing Fairy timing resources remain:

```text
timer2 = enabled
timer3 = enabled
rtc2   = enabled
```

Sensor acquisition should timestamp samples using the same Korora timing model rather than creating an unrelated timebase.

The detailed timestamp / fusion scheduling policy can be added after raw sensor data are proven.

## Prototype-to-PCB decisions this setup should answer

This prototype should provide enough evidence to freeze several Korora PCB decisions:

- whether one shared I2C bus is sufficient
- final I2C speed
- whether both data-ready interrupt lines are useful
- required sensor sample rates
- sensor-fusion CPU load
- practical fused output rate
- IMU filtering settings
- magnetometer calibration approach
- required physical separation between magnetometer and noisy hardware
- final sensor-axis orientation on the Korora PCB

The custom Korora PCB can then use the same logical topology:

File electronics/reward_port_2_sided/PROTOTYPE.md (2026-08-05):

# Nucleo master connection table

| Function | STM32 pin | Label printed beside Arduino socket | Physical Nucleo connection |
| --- | --- | --- | --- |
| SYNC capture | PA0 | A0 | CN8 pin 1 |
| Light-gate digital capture | PA1 | A1 | CN8 pin 2 |
| Audio DAC | PA4 | A2 | CN8 pin 3 |
| Light-gate ADC | PA6 | D12 | CN5 pin 5 |
| Valve PWM | PA8 | D7 | CN9 pin 8 |
| RS-485 TX | PC4 | D1 | CN5 pin 1 |
| RS-485 RX | PC5 | D0 | CN9 pin 3 |
| Optional RS-485 DE | PA12 | — | CN10 pin 12 |
| RGB channel 3 / blue | PB0 | D10 | CN5 pin 3 |
| RGB channel 1 / red | PB4 | D5 | CN9 pin 6 |
| RGB channel 2 / green | PB5 | D4 | CN9 pin 5 |
| Amplifier shutdown | PC0 | — | CN10 pin 18 |
| IR emitter enable | PC1 | — | CN10 pin 16 |
| 3.3 V | — | 3V3 | CN6 pin 4 |
| 5 V | — | 5V | CN6 pin 5 |
| Ground | — | GND | CN6 pin 6 or 7 |

# Overall power arrangement

| Supply | Use |
| --- | --- |
| Nucleo USB | MCU, programming and serial logging |
| Nucleo 3V3 | Light gate and Grove RS-485 logic |
| Nucleo 5V | RGB breakout during initial testing |
| External current-limited VLOAD | DRV8837EVM and valve |
| External regulated 5V | Preferably the audio amplifier |

---

## 1. Direct SYNC test

For the first test, do not make SYNC differential. Connect the hub GPIO directly:

| From | Through | To |
| --- | --- | --- |
| Hub SYNC output GPIO | 120 Ω series resistor | Nucleo A0 / PA0 |
| Hub GND | Direct | Nucleo GND |

The 120 Ω here is acting only as a small protective series resistor; it is **not bus termination**.

Configure the hub pin as a push-pull 3.3 V output and PA0 as TIM2_CH1 input capture.

---

## 1. Omron EE-SX1140 light gate

### Optical switch pin wiring

Identify the four Omron terminals using the `A`, `K`, `C`, and `E` markings:

| EE-SX1140 terminal | Meaning | Connect to |
| --- | --- | --- |
| A | IR LED anode | 3V3 through 100 Ω |
| K | IR LED cathode | Drain of IR-control 2N7000 |
| C | Phototransistor collector | BEAM_SENSE node |
| E | Phototransistor emitter | GND |

### BEAM_SENSE circuit

Wire the detector side like this:

```text
                  3V3
                   |
                  10k
                   |
                   +--------- PA6 / D12 / ADC
                   |
BEAM_SENSE --------+
                   |
                   +--- 1k --- PA1 / A1 / TIM2_CH2
                   |
                  470pF
                   |
                  GND

EE-SX1140 collector C -> BEAM_SENSE
EE-SX1140 emitter E   -> GND
```

PA6 gets the analogue measurement directly. PA1 receives the same node through 1 kΩ for timer capture.

## IR emitter MOSFET

Use one of the four 2N7000s:

| Connection | Wire to |
| --- | --- |
| 2N7000 source | GND |
| 2N7000 gate | PC1 / CN10 pin 16 through approximately 100–120 Ω |
| Gate pull-down | 100 kΩ from gate to GND |
| 2N7000 drain | EE-SX1140 cathode `K` |
| EE-SX1140 anode `A` | 3V3 through 100 Ω |

## 3. DFRobot RGB breakout

### Breakout connections

| DFR0239 pin | Connect to |
| --- | --- |
| `5V` / common anode | Nucleo 5V |
| `R` | Drain of red MOSFET |
| `G` | Drain of green MOSFET |
| `B` | Drain of blue MOSFET  |

### MOSFET connections

| Colour | MOSFET gate | Nucleo socket |
| --- | --- | --- |
| Red / channel 1 | PB4 | D5 |
| Green / channel 2 | PB5 | D4 |
| Blue / channel 3  | PB0 | D10 |

For each MOSFET:

```text
Nucleo PWM ---- 100 to 120 ohms ---- Gate
                                      |
                                    100k
                                      |
                                     GND

MOSFET source -> GND
MOSFET drain  -> corresponding R, G or B module pin
```

Because the breakout already contains channel resistors, do **not** add another set of 330 Ω resistors unless the LED is too bright.

## 4. DRV8837EVM and valve

### EVM wiring

| DRV8837EVM connection | Connect to |
| --- | --- |
| J1 `VM` | External current-limited VLOAD |
| J1 `GND` | External supply GND and Nucleo GND |
| TP1 `IN1` | Nucleo PA8 / D7 |
| TP2 `IN2` | GND |
| J4 `OUT1` | Valve terminal 1 |
| J4 `OUT2` | Valve terminal 2 |
| JP2 | Installed, driver active |
| EVM USB | Leave disconnected when J1 is powered |

With this wiring:

| PA8 / IN1 | IN2 | Result |
| ---: | --: | --- |
| 0 | 0 | Valve outputs coast/off |
| 1 | 0 | Valve driven |
| PWM | 0 | Drive/coast PWM |

## 5. Grove RS-485 board

Power the Grove module from **3.3 V**, rather than 5 V, so its UART-side logic remains at a Nucleo-compatible level.

| Grove RS-485 signal | Connect to Nucleo |
| --- | --- |
| Module UART input / `RX`  | PA9 / D8 / USART1_TX |
| Module UART output / `TX` | PA10 / D2 / USART1_RX  |
| VCC | 3V3 |
| GND | GND |
| A | RS-485 A on hub module |
| B | RS-485 B on hub module |

The Grove board has automatic transmit-direction control, so **PA12/DE is not connected for the prototype**. Configure USART1 for 500,000 baud, 8-N-1, normal UART mode rather than STM32 hardware-DE mode.

Across the cable:

```text
Hub module A -------- Reward-port module A
Hub module B -------- Reward-port module B
Hub ground  --------- Reward-port ground
```

## 6. PAM8302A audio prototype

With the notch or pin-1 dot used to orient the chip:

| PAM8302A pin | Function | Prototype connection |
| ---: | --- | --- |
| 1 | Active-low shutdown | PC0 / CN10 pin 18 |
| 2 | NC | Leave unconnected |
| 3 | IN+ | DAC signal through filter and 0.1 µF coupling capacitor |
| 4 | IN− | 0.1 µF capacitor to GND |
| 5 | VO+ | Speaker terminal 1 |
| 6 | VDD | Regulated 5 V |
| 7 | GND | Common GND |
| 8 | VO− | Speaker terminal 2 |

## DAC-to-amplifier input

```text
PA4 / A2
   |
   1k
   |
   +---------- 0.1uF series capacitor ---------- PAM pin 3 IN+
   |
  4.7nF
   |
  GND

PAM pin 4 IN- -------- 0.1uF -------- GND
```

## Power and shutdown

```text
5V -------- PAM pin 6
 |
 +--- 1uF --- GND
 |
 +--- 10uF -- GND

PAM pin 7 -------- GND

PC0 / CN10 pin 18 -------- PAM pin 1 SD
                              |
                            100k
                              |
                             GND
```

The pull-down keeps the amplifier shut down while the MCU is resetting. Set PC0 high to enable audio.

```text
PAM pin 5 VO+ ---- speaker ---- PAM pin 8 VO-
```

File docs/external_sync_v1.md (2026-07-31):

# Overall Architecture — External DAQ sync v1

- A moving **nRF52840 hub** owns the platform time base, trial state, event collection, buffering, and direct BLE communication with the main computer.
- A second, stationary **nRF52840 timing bridge** sits beside the DAQ. It maintains a hardware-clock relationship with the moving hub over BLE and generates future-timestamped TTL synchronization markers for the DAQ.
- The DAQ records TTL edges in its own sample-clock domain and sends its data to the computer over USB.
- Behavioural event data remains direct, the stationary bridge is not a data relay.

```text
                               STATIONARY SIDE
                      ┌──────────────────────────┐
                      │ Main computer            │
                      │                          │
                      │ Platform event receiver  │
                      │ DAQ recording software   │
                      │ Alignment and storage    │
                      └──────^───────────^───────┘
                             │ BLE       │ USB
                             │           │
          MOVING PLATFORM    │           │
 ┌───────────────────────────┴────┐   ┌──┴─────────────────┐
 │ CENTRAL HUB — nRF52840         │   │ External DAQ/ephys │
 │                                │   │                    │
 │ Trial state machine            │   │ Neural/analogue    │
 │ Command scheduler              │   │ acquisition clock  │
 │ Raw logging and buffering      │   │ Digital TTL input  │
 │ Direct BLE data to computer    │   └────────^───────────┘
 │                                │            │ TTL
 │ Platform timing authority      │   ┌────────┴───────────┐
 │   ├── 1 MHz TIMEBASE           │   │ Stationary nRF52840│
 │   ├── periodic SYNC            │   │ timing bridge      │
 │   └── 64-bit platform time     │   │                    │
 │                                │<->│ BLE clock mapping  │
 │ RS-485 master                  │   │ TTL OUT / TTL IN   │
 │ Battery and regulated rails    │   │                    │
 └──────────────┬─────────────────┘   └────────────────────┘
                │
                │ Power, RS-485, TIMEBASE, SYNC
                │ Electrically linear trunk
                │
 ┌──────────────v────────────────────────────────────────┐
 │ REWARD-PORT MCU — STM32G071-class                     │
 │                                                       │
 │ Shared-time timer                                     │
 │   ├── beam-break hardware capture                     │
 │   ├── scheduled RGB output compare                    │
 │   ├── scheduled audio start                           │
 │   └── scheduled valve pulse                           │
 │                                                       │
 │ Event ring buffer and sequence IDs                    │
 │ RGB driver | audio driver | solenoid MOSFET | spares  │
 └───────────────────────────────────────────────────────┘
```

## Decisions — TLDR

- **DAQ data path —** DAQ has it’s own data path and time sync with the computer, does not interact with floating platform event system
- **Added MCU —** DAQ gets a small BLE capable MCU (like nRF52840) which will be used for TTL generation
- **Future stamped BLE TTL generation —** Floating platform chip can time sync with the DAQ MCU to ~4us, sending a future TTL signal with a known timestamp gives a generated TTL for the DAQ on the order of 5-10us

## Assumptions about the existing system

- **Floating platform hub —** An nRF52840 (or equivalent) based hub collects timestamped records from all reward ports and owns platform time. It supports direct BLE communication to the main computer and a second BLE timing connection to a stationary bridge.
- **External DAQ —** The DAQ records TTL transitions against its hardware sample clock and reports its acquired data to the computer over USB. Its input and sample quantization error is represented by $e_d$
- **Computer —** The computer stores both streams and performs alignment. Operating system BLE or USB packet arrival time is not treated as the experimental timestamp.
- **Stationary timing bridge —** A stationary nRF52840 (or equivalent) near the DAQ maps its hardware timer to the moving hub timer and converts scheduled platform timestamps into hardware TTL edges

---

# 1. External DAQ and electrophysiology synchronization

## Architecture

The moving platform remains untethered. A stationary nRF52840 timing bridge is installed beside the external DAQ:

```text
MOVING HUB                                  STATIONARY RIG

platform_tick H
event buffering ───── BLE direct ─────────► computer
      │
      └──── BLE clock synchronization ────► stationary nRF
                                             │
                                             ├── TTL OUT → DAQ digital input
                                             ├── TTL IN  ← DAQ/laser output
                                             └── USB diagnostics → computer

DAQ/ephys ───────────── USB/data link ─────► computer
```

## Two BLE connections

The moving hub supports two concurrent BLE links:

### Link A — hub to computer

The computer acts as Central, The moving hub acts as Peripheral and exposes experiment-data and control services.

Traffic includes:

- reward-port events
- IMU records
- executed cue and reward events
- sequence IDs
- health information
- trial configuration and commands

### Link B — hub to stationary timing bridge

The moving hub acts as Central. The stationary bridge acts as Peripheral.

Traffic is low volume:

- connection-anchor timing information
- clock-quality updates
- future synchronization-marker schedules
- pulse IDs and widths
- bridge status
- execution acknowledgements

## BLE clock synchronization method

The selected baseline is Nordic connection time synchronization over a normal BLE ACL connection.

Both devices observe BLE connection event anchor points in their own local clock domains. The moving hub sends its anchor reference to the stationary bridge. The bridge estimates:

$S = a_{hs}H + b_{hs}$

Nordic's sample demonstrates microsecond scale synchronized timed triggers on supported hardware, including nRF52840 development kits. This is a reference implementation but it serves well to show target scaling of errors.

Bluetooth ISO time synchronization remains an alternative if one source must synchronize several independent receivers or if ISO transport is otherwise needed. It is not required for a single stationary bridge.

## Future timestamped TTL markers

Precision synchronization should use a future timestamp, not a “toggle when this BLE packet arrives” command.

Example:

```text
SYNC_SCHEDULE:
  sync_id          = 105
  hub_trigger_tick = 80,000,000
  pulse_width_us   = 1,000
```

The stationary bridge:

1. converts `hub_trigger_tick` into stationary time
2. verifies that the command arrived before the minimum arm deadline
3. programs a hardware timer compare
4. uses timer/PPI/GPIOTE to toggle the output without an RTOS callback
5. records scheduled and actual local trigger timestamps
6. reports success or failure

The BLE message may arrive with variable latency. That latency does not affect the TTL edge if the marker is armed in time.

A `FIRE_NOW` command may be retained for wiring tests and latency measurements but shouldn't be used as the scientific synchronization reference.

## DAQ recording and USB transport

The DAQ records the TTL transition against its own hardware sample clock:

```text
sync_id 105:
  hub timestamp = H105
  DAQ sample     = D105
```

USB transports the already acquired DAQ data to the computer. USB buffer or callback latency does not alter the DAQ sample index if timestamping occurs in DAQ hardware.

With repeated synchronization pairs:
$D_k = \alpha H_k + \beta$

the computer estimates the offset and relative clock rate between platform time and DAQ time. A platform event at timestamp \(H_e\) is translated to:
$D_e = \alpha H_e + \beta$

Coeffs of the linear transformation should stay stable throughout the experimental runtime.

## Marker identification

Every marker should have a monotonically increasing `sync_id`.

Regular anonymous 1 Hz pulses can become ambiguous after:

- a missed pulse
- DAQ restart
- BLE reconnect
- partial recording

Recommended approach:

- regular timing pulses
- periodic distinctive barcode bursts or pseudo-random intervals
- explicit marker IDs in hub and bridge logs
- start of session and reconnection epoch markers

## Bidirectional TTL

The bridge should provide:

```text
SYNC_OUT -> DAQ digital input
SYNC_IN  <- DAQ or electrophysiology digital output
```

This supports:

- hub-master synchronization
- DAQ-master synchronization
- additional validation
- measurement of output and input path delay
- compatibility with systems that already expose sync clocks

## Optic control

The stationary bridge may provide a separate TTL output for laser control. The laser event is known in advance and can be armed at an absolute platform timestamp. This is compatible with hardware timer scheduling and deterministic onset.

(maybe not needed at all)

---

# 2. Validation plan

## Internal timing validation

Using an oscilloscope to compare:

- hub TIMEBASE at source
- TIMEBASE at first, middle, and final reward ports
- SYNC edges at all modules
- scheduled output edges from multiple modules
- captured beam-test edges

Measuring:

- propagation delay
- channel-to-channel skew
- jitter
- missed edge rate
- offset stability over temperature and full session duration

## Wireless bridge validation

Generating future timestamped outputs on both hub and stationary bridge and observe them simultaneously. We test:

- normal radio conditions
- maximum event traffic
- two active BLE connections
- BLE retransmissions
- reconnection
- multi hour drift
- minimum and maximum connection intervals under consideration

## End-to-end DAQ validation

During development, we produce synthetic sync events. Fit the clock map and calculate residual error.

Provisional acceptance targets:

- no clock discontinuities
- no unidentified marker loss
- no systematic error growth through a multi-hour session
- 95th-percentile absolute alignment error ≤0.5 ms
- 99th-percentile absolute alignment error ≤1.0 ms

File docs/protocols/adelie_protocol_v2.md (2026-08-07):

# Adelie command protocol v2

Adelie v2 carries commands from the Python application and responses from the target board. Commands use a fixed header and flexible TLV fields.

## Message header

| Offset | Size | Field | Meaning |
| -----: | ---: | --- | --- |
| 0 | 2 | magic | `0xAD1E` |
| 2 | 1 | version | `2` |
| 3 | 1 | header size | `32` |
| 4 | 1 | kind | Command or response |
| 5 | 1 | status | Response status |
| 6 | 2 | opcode | Requested operation |
| 8 | 2 | flags | Command behavior |
| 10 | 4 | command ID | Duplicate and response correlation |
| 14 | 4 | session ID | Active experiment session |
| 18 | 8 | execute at ticks | Target local time or zero |
| 26 | 4 | deadline ms | Sender timeout guidance |
| 30 | 2 | payload length | TLV payload bytes |
| 32 | N | payload | TLV fields |

Kind 1 is a command. Kind 2 is a response. The TLV encoding and value types are the same as Fairy v3.

## Command flags

| Bit | Name | Meaning |
| --: | --- | --- |
| 0 | require response | Sender expects a response |
| 1 | execute immediately | No future scheduling is requested  |
| 2 | replace existing | Replace a compatible queued action |
| 3 | safety authorized | Required for a valve action |

## Status values

| Value | Name |
| ----: | --- |
| 0 | ok |
| 1 | accepted |
| 2 | busy |
| 3 | bad message |
| 4 | unsupported |
| 5 | invalid state |
| 6 | invalid parameter  |
| 7 | not synchronized |
| 8 | inventory mismatch |
| 9 | timeout |
| 10 | transport error |
| 11 | queue full |
| 12 | duplicate |
| 13 | safety lock |
| 14 | session mismatch |
| 15 | internal error |

`accepted` means the command was queued. Final execution is reported with a Fairy `command result` record.

## Core operations

| Value | Name | Target |
| ---: | --- | --- |
| `0x0001` | ping | Any board |
| `0x0002` | get inventory | Korora |
| `0x0003` | apply inventory | Korora |
| `0x0004` | identify | Fairy |
| `0x0005` | get health | Any board |
| `0x0006` | clear faults | Any board |
| `0x0007` | set telemetry | Korora |
| `0x0008` | clock exchange  | Korora |
| `0x0100` | start session | Korora and propagated boards |
| `0x0101` | stop session | Korora and propagated boards |
| `0x0200` | set RGB | Fairy |
| `0x0201` | set IR | Fairy |
| `0x0202` | set audio | Fairy |
| `0x0203` | actuate valve | Fairy |
| `0x0204` | configure valve | Fairy |
| `0x0205` | configure pins  | Reserved Fairy extension |
| `0x0300` | schedule TTL | Galapagos |
| `0x0301` | start TTL train | Korora |
| `0x0302` | stop TTL train  | Korora |
| `0x0400` | start sync test | Korora |
| `0x0401` | stop sync test  | Korora |

## Important command fields

| Value | Name | Type |
| ---: | --- | --- |
| `0x1000` | telemetry level | Unsigned 8 bit  |
| `0x1001` | UUID list | Bytes |
| `0x1003` | identify duration ms | Unsigned 32 bit |
| `0x1010` | red | Unsigned 8 bit  |
| `0x1011` | green | Unsigned 8 bit  |
| `0x1012` | blue | Unsigned 8 bit  |
| `0x1020` | audio mode | Unsigned 8 bit  |
| `0x1021` | frequency Hz | Unsigned 32 bit |
| `0x1022` | low frequency Hz | Unsigned 32 bit |
| `0x1023` | high frequency Hz | Unsigned 32 bit |
| `0x1024` | amplitude | Unsigned 16 bit |
| `0x1025` | duration ms | Unsigned 32 bit |
| `0x1030` | spike duration us | Unsigned 32 bit |
| `0x1031` | spike duty per mille | Unsigned 16 bit |
| `0x1032` | hold duty per mille | Unsigned 16 bit |
| `0x1033` | maximum on time us | Unsigned 32 bit |
| `0x1034` | minimum interval us | Unsigned 32 bit |
| `0x1035` | VLOAD millivolts | Unsigned 32 bit |
| `0x1040` | TTL frequency millihertz | Unsigned 32 bit |
| `0x1041` | TTL width us | Unsigned 32 bit |
| `0x1042` | TTL count | Unsigned 32 bit |
| `0x1043` | sequence | Unsigned 32 bit |
| `0x1050` | test command interval ms | Unsigned 32 bit |
| `0x1060` | clock t1 ns | Unsigned 64 bit |
| `0x1061` | clock t2 ticks | Unsigned 64 bit |
| `0x1062` | clock t3 ticks | Unsigned 64 bit |

## Inventory encoding

`get inventory` returns `UUID list` as zero or more 18 byte entries:

| Offset | Size | Meaning |
| -----: | ---: | --- |
| 0 | 12 | STM32 factory UUID |
| 12 | 1 | Current transport address |
| 13 | 1 | Zero based Fairy index or `0xFF` |
| 14 | 4 | Capability bits |

`apply inventory` uses 13 byte entries:

| Offset | Size | Meaning |
| -----: | ---: | --- |
| 0 | 12 | UUID |
| 12 | 1 | Fairy index from 0 to one less than the configured maximum |

Korora accepts the list only when:

- Entry count equals the complete live Fairy count
- Every live UUID appears exactly once
- No unknown UUID appears
- Every Fairy index is valid and unique

## Sessions

A normal session can start only when the exact inventory is assigned, every Fairy clock model is valid, Galapagos is connected, and its clock model is valid.

Commands that affect experiment outputs carry the active session ID. A mismatch is rejected.

If Adelie disconnects, Korora stops the active session and sends outputs to safe state. Health and synchronization continue.

## Audio modes

| Value | Mode |
| ----: | --- |
| 0 | Off |
| 1 | Tone |
| 2 | Band limited white noise |

## TTL train

Adelie sends frequency in millihertz, width in microseconds, and an optional count. Count zero means continuous. This implementation accepts 0.1 Hz to 10 Hz. Korora schedules each pulse in its clock and converts the target into the Galapagos clock.

The recorded sequence is:

1. Korora emits `TTL scheduled`
2. Galapagos emits `TTL generated`
3. Korora captures the prototype loopback and emits `TTL captured`
4. Korora emits `TTL result` with signed error in nanoseconds

## Sync test

Start sync test:

- Selects full telemetry
- Starts a 1 Hz TTL train
- Sends a safe random RGB command once per second
- Leaves valve commands disabled

Stop sync test restores standard telemetry and stops the diagnostic TTL train.

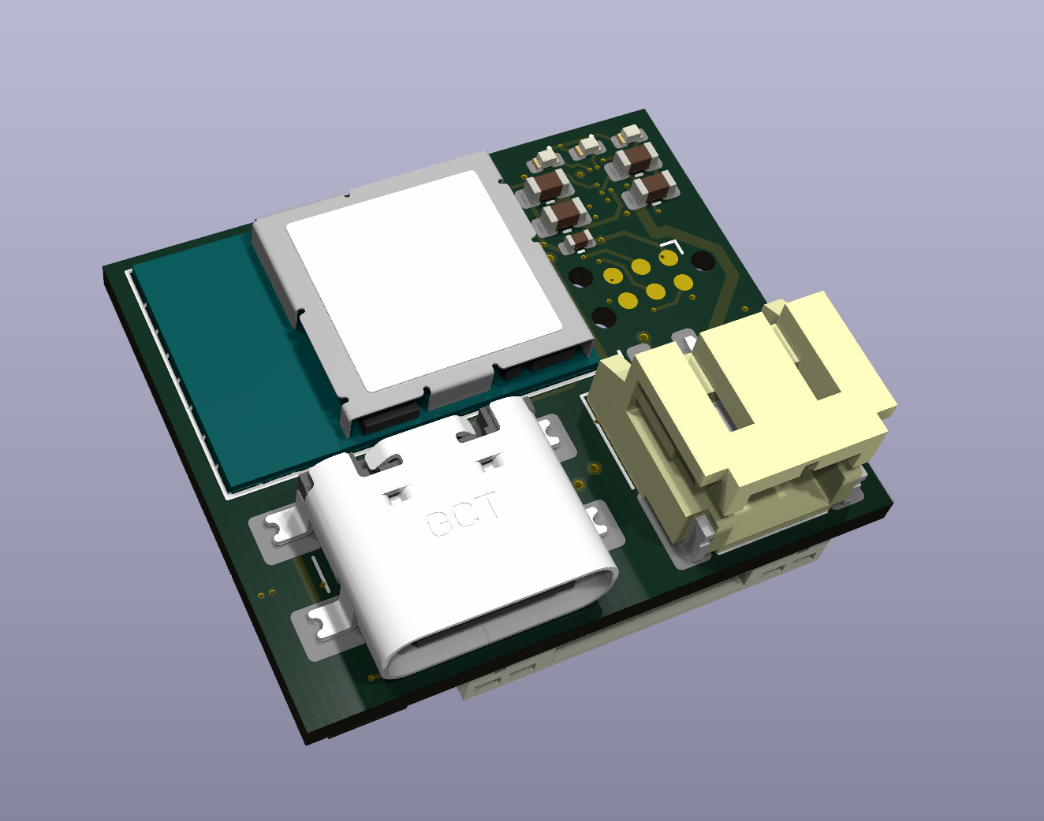
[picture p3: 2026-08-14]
assets/floating_hub_3d_model.png

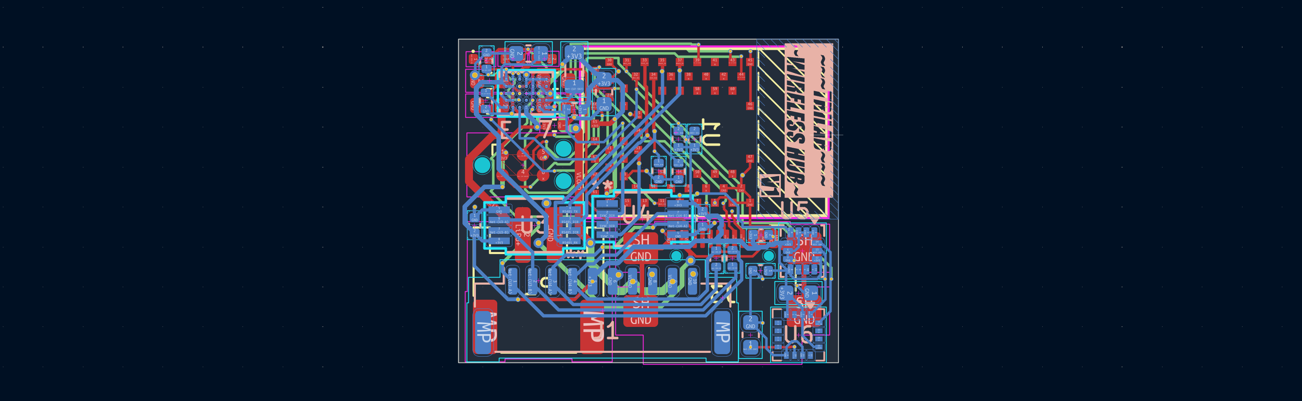
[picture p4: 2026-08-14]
assets/floating_hub_pcb_long.png

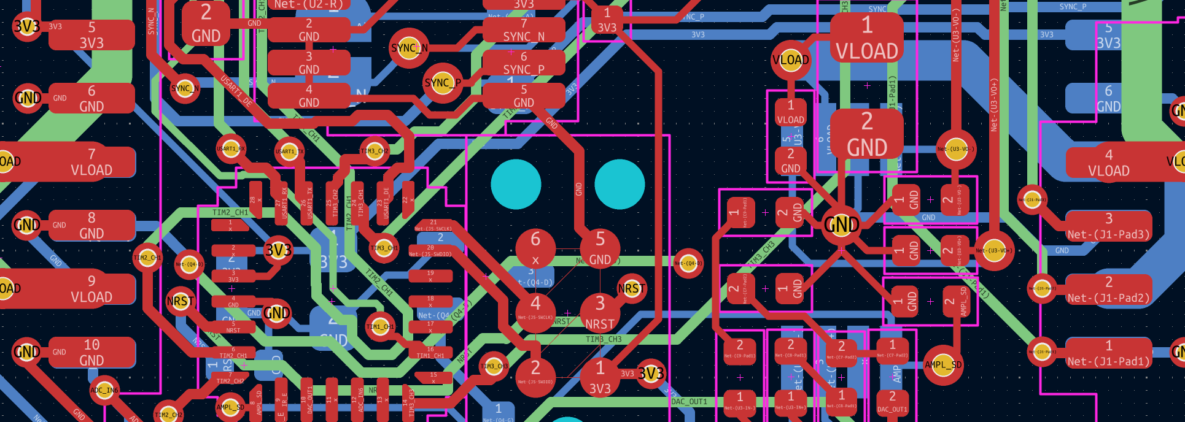
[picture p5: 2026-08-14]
assets/pcb_closeup.png

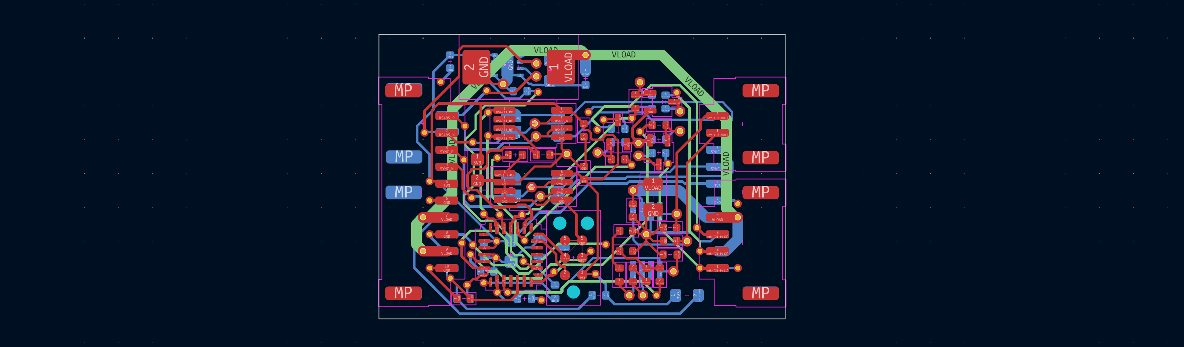
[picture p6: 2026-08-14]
assets/reward_port_pcb_long.png

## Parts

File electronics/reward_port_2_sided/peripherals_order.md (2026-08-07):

# Peripherals

| Item | Qty | Farnell or RS link | Note |
| --- | --: | --- | --- |
| PUI Audio AS01508MR-6-LW100-R speaker |  5x | [Farnell 4411338](https://uk.farnell.com/pui-audio/as01508mr-6-lw100-r/speaker-900-20khz-8-ohm-88db/dp/4411338) | |
| 5 mm common-anode RGB LED |  1x | [RS Components 254-5725](https://uk.rs-online.com/web/p/leds/2545725) | Pack of 5 units |

# Wires

| Item | Qty to order | Farnell or RS link | Note |
| --- | ---: | --- | --- |
| JST-GH 2-pin housing, GHR-02V-S | 1x | [RS 752-1734](https://uk.rs-online.com/web/p/wire-housings-plugs/7521734) | Housings, pack of 10 |
| JST-GH 4-pin housing, GHR-04V-S | 1x | [RS 752-1731](https://uk.rs-online.com/web/p/wire-housings-plugs/7521731) | Housings, pack of 10 |
| JST-GH 10-pin housing, GHR-10V-S | 1x | [RS 752-1756](https://uk.rs-online.com/web/p/wire-housings-plugs/7521756) | Housings, pack of 10 |
| JST-GH double-ended pre-crimped wire, 150 mm, white | 11x | [RS 820-1393](https://uk.rs-online.com/web/p/crimped-wire/8201393) | Wires! |

# Extra cables

| Item | Qty to order | Farnell or RS link | Note |
| --- | ---: | --- | --- |
| TEN01014 | 1 | [Farnell 3498555](https://uk.farnell.com/tenma/ten01014/test-lead-set-4mm-plug-croc-clip/dp/3498555) | Bench PSU to crocodile |
| TC2030 cable | 1 | [TagConnect](https://www.tag-connect.com/product/tc2030-ctx-nl-stdc14-for-use-with-stm32-processors-with-stlink-v3) | |
| STLink-V3SET | 1 | [Mouser](https://www.mouser.co.uk/en/ProductDetail/STMicroelectronics/STLINK-V3SET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) | Has STDC14 |
| STLink-V3PWR | 1 | [Farnell 4158077](https://uk.farnell.com/stmicroelectronics/stlink-v3pwr/debugger-prog-tool-stm32-arm-cortex/dp/4158077) | Only if we really want to order from farnell |

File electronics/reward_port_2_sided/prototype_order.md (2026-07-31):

# Required

| Item | Qty | Farnell or RS link | Note |
| --- | --: | --- | --- |
| Omron `EE-SX1140` |  1x | [Farnell 1348958](https://uk.farnell.com/omron-electronic-components/ee-sx1140/photo-interrupter-transmissive/dp/1348958) | Should be the same lightgate as on the original |
| Power Management IC Development Kit Motor Driver for DRV8837 |  1x | [RS components 2659774](https://uk.rs-online.com/web/p/power-motor-robotics-development-tools/2659774) | H-Bridge breakout board |
| DFRobot common-anode RGB LED breakout, `DFR0239`, with straight 4-pin header |  1x | [Farnell 4308179](https://uk.farnell.com/dfrobot/dfr0239/rgb-led-breakout-5v-13x13mm/dp/4308179) |
| Diotec `2N7000` through-hole N-channel MOSFET |  4x | [Farnell 4555444](https://uk.farnell.com/diotec/2n7000/mosfet-n-channel-60v-0-2a-to-92/dp/4555444) |

## Kinda required

| Item | Qty | Farnellor RS link | Note |
| --- | ---: | --- | --- |
| Diodes Inc. PAM8302AADCR mono Class-D amplifier, SOIC-8 | 1x | [Farnell 3373818](https://uk.farnell.com/diodes-inc/pam8302aadcr/audio-power-amp-d-40-to-85deg/dp/3373818) | Only if doing audio |
| Aries LCQT-SOIC8-8 SOIC-8 to DIP adapter | 1x | [Farnell 2476033](https://uk.farnell.com/aries/lcqt-soic8-8/ic-adaptor-8-soic-to-dip-2-54mm/dp/2476033) | Only if doing audio |
| PUI Audio `AS02808MR-LW152-R` speaker | 1x | [Farnell 4411359](https://uk.farnell.com/pui-audio/as02808mr-lw152-r/speaker-500hz-20khz-8ohm-95dba/dp/4411359) | Only if we are doing audio |
| Seeed Studio `103020193` Grove RS-485 board | 2(hub)+2x | [Farnell 4007772](https://uk.farnell.com/seeed-studio/103020193/serial-comm-board-rs485-arduino/dp/4007772) | I need at least 4 RS-485 transcievers for a full implementaion (can do it with 1+1x since sync doesn't have to be differential on the test) |
| Seeed Studio Grove 4-pin to male-jumper conversion cable, pack of 5, `110990210` | 1 | [Farnell 3410135](https://uk.farnell.com/seeed-studio/110990210/cable-4-pin-male-jumper-grove/dp/3410135) | Connectors for transcievers because they are annoying |
| Multicomp Pro `MF25 120R`, 120 Ω, 1%, ¼ W through-hole resistor | 3x | [Farnell 9341218](https://uk.farnell.com/multicomp-pro/mf25-120r/res-120r-1-0-25w-axial-metal-film/dp/9341218)  | Not an exact necessity but they are useful for RS485 trunk termination |
| Multicomp Pro `MC01006`, 45 × 91 mm, 2.54 mm matrix perfboard | 2x | [Farnell 2768276](https://uk.farnell.com/multicomp-pro/mc01006/prototype-board-phenolic-91mm/dp/2768276) | Fire safety precaution |

# Nice to haves

| Item | Qty | Farnell or RS link | Note |
| --- | --: | --- | --- |
| Bud Industries `BC-32625` assorted-length male-to-male jumper wires, 65 pieces | 1 | [Farnell 2762505](https://uk.farnell.com/bud-industries/bc-32625/jump-wire-bundle-solderless-bread/dp/2762505) | When already ordering a bunch of wires would come in handy |
| DFRobot `FIT0121` assorted-length male-to-female jumper wires, 65 pieces | 1 | [Farnell 3769939](https://uk.farnell.com/dfrobot/fit0121/jumper-wire-set-65pc-female-to/dp/3769939) |
| Harwin `D01-9922046` breakaway male 2.54 mm header, 20 pins | 1 | [Farnell 1022217](https://uk.farnell.com/harwin/d01-9922046/conn-hdr-20pos-1row-2-54mm/dp/1022217) |
| Samtec `SSA-120-S-T` breakaway female 2.54 mm socket strip, 20 pins | 1 | [Farnell 3550851](https://uk.farnell.com/samtec/ssa-120-s-t/conn-rcpt-20pos-1row-2-54mm/dp/3550851) |

# Soldering iron tips

| Item | Qty | Farnell link |
| --- | --: | --- |
| Multicomp Pro `MP740228`, 1.6 mm chisel tip | 1 | [Farnell 3265141](https://uk.farnell.com/multicomp-pro/mp740228/soldering-tip-chisel-1-6mm/dp/3265141) |
| Multicomp Pro `MP740229`, 2.4 mm chisel tip | 1 | [Farnell 3265142](https://uk.farnell.com/multicomp-pro/mp740229/soldering-tip-chisel-2-4mm/dp/3265142) |
| Multicomp Pro `MP740236`, 0.4 mm bent-point tip | 1 | [Farnell 3265150](https://uk.farnell.com/multicomp-pro/mp740236/soldering-tip-pointed-bent-0-4mm/dp/3265150) |
| Multicomp Pro `MP740232`, 0.5 mm straight-point tip | 1 | [Farnell 3265145](https://uk.farnell.com/multicomp-pro/mp740232/soldering-tip-pointed-0-5mm/dp/3265145) |

# Project will fall apart without these

| Item | Link |
| --- | --- |
| Assorted industrial communication cables | [Mouser 595-SK-AM64B ](https://www.mouser.co.uk/en/ProductDetail/Texas-Instruments/SK-AM64B?qs=dbcCsuKDzFUm4q0JHqB%2F9Q%3D%3D) |
| BLE evaluation platform | [Farnell 4803865](https://uk.farnell.com/ezurio/453-00197-k1/dev-board-bluetooth-low-energy/dp/4803865) |
| Programmable red breadboard | [Farnell 4262565](https://uk.farnell.com/beagleboard/102110898/sbc-beaglev-fire-risc-v-fpga/dp/4262565) |

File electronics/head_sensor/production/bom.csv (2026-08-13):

Designator | Footprint | Quantity | Value | LCSC Part #
C1 | 0603 | 1 | 4.7uF
C2, C4 | 0402 | 2 | 1uF
C3, C5 | 0402 | 2 | 100nF
C6 | 0603 | 1 | 10uF
J1 | OMNETICS_A79607-001 | 1 | A79608-001
Q1 | Diodes_DFN1006-3 | 1 | DMN2300UFB4-7B
R1, R2 | 0402 | 2 | 620
R3 | 0402 | 1 | 110
R4 | 0402 | 1 | 10k
R5 | 0402 | 1 | 100k
U1 | UFD_05-08-1711_ADI | 1 | LTC4332IUFD-PBF
U2 | LGA-14_3x2.5mm_P0.5mm_LayoutBorder3x4y | 1 | LSM6DSV32XTR
U3 | LGA-16_3x3mm_P0.5mm | 1 | MMC5983MA

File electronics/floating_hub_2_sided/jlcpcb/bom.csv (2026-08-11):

Comment | Designator | Footprint | LCSC Part #
1uF 16V X5R | C1,C6,C13 | C_0603_1608Metric | C106215
2.2uF 10V X7R | C2 | C_0603_1608Metric | C100082
10uF 10V X5R | C3,C4,C5,C10 | C_0603_1608Metric | C109453
100nF 16V X7R | C7,C8,C9,C11,C12 | C_0402_1005Metric | C169842
LED Red - SZYY0402R | D1 | LED_0402_1005Metric | C434445
LED Green - GL0402UG01 | D2 | LED_0402_1005Metric | C51933302
LED Blue - XL-1005UBC | D3 | LED_0402_1005Metric | C22355736
SM10B-GHS-TB | J1 | JST_GH_SM10B-GHS-TB_1x10-1MP_P1.25mm_Horizontal | C2683602
USB4110-GF-A | J3 | USB_C_Receptacle_GCT_USB4110 | C5143397
2.2uH 0805 - ZEPIM201265S-2R2M | L1 | L_0805_2012Metric | C48945047
S2B-PH-SM4-TB(LF)(SN) | P1 | JST_PH_S2B-PH-SM4-TB_1x02-1MP_P2.00mm_Horizontal | C295747
10k 1% | R1,R3,R4,R5 | R_0402_1005Metric | C25744
330k 1% | R2 | R_0402_1005Metric | C138006
2.7k 5% | R6,R9 | R_0402_1005Metric | C25935
120R 1% | R7,R8 | R_0402_1005Metric | C25079
KMR231GLFS tactile switch | SW1 | SW_Push_1P1T_NO_CK_KMR2 | C99271
BMD-340-A-R | U1 | BMD-340_UBL | C5456944
NPM1300-CAAA-R7 | U2 | WLCSP35_2p3775X3p0775_NOR | C25346894
SN65HVD75DGKR | U3,U4 | DGK8_TEX | C179693
LSM6DSV32XTR | U5 | LGA-14_3x2.5mm_P0.5mm_LayoutBorder3x4y | C22461202
MMC5983MA | U6 | LGA-16_3x3mm_P0.5mm | C404329

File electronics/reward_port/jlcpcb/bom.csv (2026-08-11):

Comment | Designator | Footprint | LCSC Part #
10uF 10V X5R +/-10% | C1, C19 | 0603 | C19702
1uF 25V X5R +/-10% | C2, C10 | 0402 | C52923
100nF 16V X7R +/-10% | C3, C4, C8, C9, C14, C15, C16, C20 | 0402 | C60474
470pF 50V NP0 +/-5% | C5 | 0402 | C106259
4.7uF 10V X5R +/-10% | C6, C17 | 0603 | C1705
4.7nF 50V X7R +/-10% | C7 | 0402 | C84705
220pF 50V NP0 +/-5% | C11, C12 | 0402 | C107001
10uF 25V X5R +/-10% | C13 | 0805 | C15850
TPSE477M010R0100 | C18 | CASE-E-7343-43 | C308821
JST GH 4-position right-angle SMD header, 1.25mm | J1, J4 | JST GH 1x4 P1.25mm RA SMD | C51940118
JST GH 10-position right-angle SMD header, 1.25mm | J2, J3 | JST GH 1x10 P1.25mm RA SMD | C2683602
JST GH 2-position right-angle SMD header, 1.25mm | J6, J7 | JST GH 1x2 P1.25mm RA SMD | C189893
N-channel MOSFET 60V 310mA | Q1, Q2, Q3, Q4 | SOT-323 (SC-70) | C255579
120ohm +/-1% 0.1W | R1, R2 | 0603 | C22787
10kohm +/-1% 0.0625W | R3, R15, R23 | 0402 | C25744
330ohm +/-1% 0.0625W | R4, R5, R6 | 0402 | C25104
100kohm +/-1% 0.0625W | R7, R8, R9, R18, R20, R21, R22 | 0402 | C25741
100ohm +/-1% 0.0625W | R10, R11, R12, R19 | 0402 | C25076
33ohm +/-1% 0.0625W | R13 | 0402 | C25105
100ohm +/-1% 0.1W | R14 | 0603 | C22775
1kohm +/-1% 0.0625W | R16, R17 | 0402 | C11702
SN65HVD75DGKR | U1, U2 | VSSOP-8 3x3mm P0.65mm | C179693
2.5W mono Class-D audio amplifier | U3 | MSOP-8 | C113367
STM32G071 MCU, 128KB flash | U4 | UFQFPN-28 4x4mm P0.5mm | C529347
Low-voltage H-bridge motor/solenoid driver | U5 | WSON-8-EP 2x2mm P0.5mm | C39159

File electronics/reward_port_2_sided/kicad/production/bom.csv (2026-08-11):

Designator | Footprint | Quantity | Value | LCSC Part #
C1, C19 | 0603 | 2 | 10uF
C10 | 0402 | 1 | 1uF
C11, C12 | 0402 | 2 | 220pF
C13 | 0805 | 1 | 10uF
C14, C15, C16, C20, C3, C4, C8, C9 | 0402 | 8 | 100nF
C17 | 0603 | 1 | 4.7uF
C18 | CP_EIA-7343-43_Kemet-X | 1 | 470uF
C5 | 0402 | 1 | 470pF
C7 | 0402 | 1 | 4.7nF
J1, J4 | JST_GH_SM04B-GHS-TB_1x04-1MP_P1.25mm_Horizontal | 2 | SM04B-GHS-TB
J2, J3 | JST_GH_SM10B-GHS-TB_1x10-1MP_P1.25mm_Horizontal | 2 | SM10B-GHS-TB
J6, J7 | JST_GH_SM02B-GHS-TB_1x02-1MP_P1.25mm_Horizontal | 2 | SM02B-GHS-TB
Q1, Q2, Q3, Q4 | SOT-323_SC-70 | 4 | 2N7002PW
R1, R2 | 0603 | 2 | 120
R10, R11, R12, R19 | 0402 | 4 | 100
R13 | 0402 | 1 | 33
R14 | 0603 | 1 | 100
R15, R23, R3 | 0402 | 3 | 10k
R16, R17 | 0402 | 2 | 1k
R18, R20, R21, R22, R7, R8, R9 | 0402 | 7 | 100k
R4, R5, R6 | 0402 | 3 | 330
U1, U2 | VSSOP-8_3x3mm_P0.65mm | 2 | THVD1410DGKR
U3 | PAM8302AASCR_DIO | 1 | PAM8302AASCR
U4 | QFN-28_4x4mm_P0.5mm | 1 | STM32G071GBU6
U5 | WSON-8-1EP_2x2mm_P0.5mm_EP0.9x1.6mm | 1 | DRV8837

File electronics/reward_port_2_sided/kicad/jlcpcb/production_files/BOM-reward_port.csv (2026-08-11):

Comment | Designator | Footprint | LCSC | Quantity
100 | R14 | R_0603_1608Metric | C22775 | 1
100 | R10,R11,R12,R19 | R_0402_1005Metric | C25076 | 4
100k | R18,R20,R21,R22,R7,R8,R9 | R_0402_1005Metric | C25741 | 7
100nF | C14,C15,C16,C20,C3,C4 | C_0402_1005Metric | C307331 | 6
100nf | C8,C9 | C_0402_1005Metric | C307331 | 2
10k | R15,R23,R3 | R_0402_1005Metric | C25744 | 3
10uF | C13 | C_0805_2012Metric | C440198 | 1
10uF | C1,C19 | C_0603_1608Metric | C96446 | 2
120 | R1,R2 | R_0603_1608Metric | C14709 | 2
1k | R16,R17 | R_0402_1005Metric | C11702 | 2
1uF | C10 | C_0402_1005Metric | C52923 | 1
220pF | C11,C12 | C_0402_1005Metric | C1530 | 2
2N7002PW | Q1,Q2,Q3,Q4 | SOT-323_SC-70 | C5224236 | 4
33 | R13 | R_0402_1005Metric | C25105 | 1
330 | R4,R5,R6 | R_0402_1005Metric | C25104 | 3
4.7nF | C7 | C_0402_1005Metric | C1538 | 1
4.7uF | C17 | C_0603_1608Metric | C19666 | 1
470pF | C5 | C_0402_1005Metric | C1537 | 1
470uF | C18 | CP_EIA-7343-43_Kemet-X | C506631 | 1
DRV8837 | U5 | WSON-8-1EP_2x2mm_P0.5mm_EP0.9x1.6mm | C39159 | 1
PAM8302AASCR | U3 | PAM8302AASCR_DIO | C113367 | 1
SM02B-GHS-TB | J6,J7 | JST_GH_SM02B-GHS-TB_1x02-1MP_P1.25mm_Horizontal | C189893 | 2
SM04B-GHS-TB | J1,J4 | JST_GH_SM04B-GHS-TB_1x04-1MP_P1.25mm_Horizontal | C51940118 | 2
SM10B-GHS-TB | J2,J3 | JST_GH_SM10B-GHS-TB_1x10-1MP_P1.25mm_Horizontal | C2683602 | 2
STM32G071GBU6 | U4 | QFN-28_4x4mm_P0.5mm | C529347 | 1
THVD1410DGKR | U1,U2 | VSSOP-8_3x3mm_P0.65mm | C179693 | 2

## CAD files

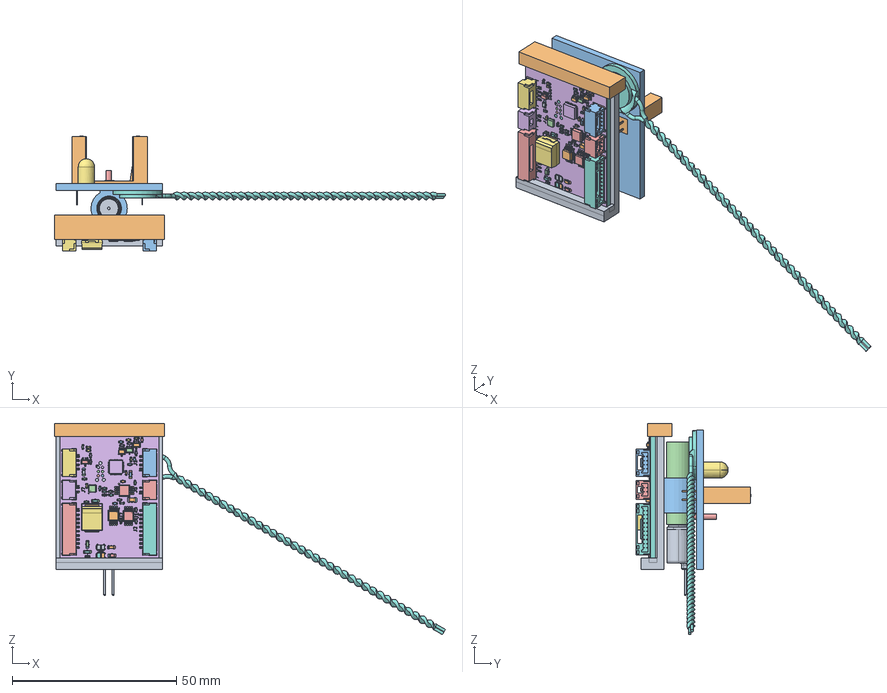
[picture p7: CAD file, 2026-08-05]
electronics/reward_port/reward_port_full.FCStd
118.9 x 34.9 x 64.3 mm
Lee-LHD_Series-2-Port_Plug-In-CAD_Model A2
EE_SX1140
WP154A4SEJ3VBDZGC_CA
WP154A4SEJ3VBDZGC_CA001
WP154A4SEJ3VBDZGC_CA002
WP154A4SEJ3VBDZGC_CA003
WP154A4SEJ3VBDZGC_CA004
AS01508MR-6-LW100-R
AS01508MR-6-LW100-R001
AS01508MR-6-LW100-R002
AS01508MR-6-LW100-R003
Milk_Holder
Milk Valve
R_0402_1005Metric
C_0402_1005Metric
C_0402_1005Metric002
C_0402_1005Metric004
R_0402_1005Metric002
R_0402_1005Metric004
WSON_8_1EP_2x2mm_P05mm_EP09x16mm
JST_SM10B_GHS_TB
QFN_28_4x4mm_P05mm
R_0402_1005Metric006
C_0603_1608Metric
C_0402_1005Metric006
C_0402_1005Metric008
JST_SM04B_GHS_TB
R_0402_1005Metric008
VSSOP-8_3x3mm_P0.65mm
R_0402_1005Metric010
JST_SM04B_GHS_TB001
C_0402_1005Metric010
C_0402_1005Metric012
R_0603_1608Metric
C_0402_1005Metric014
C_0402_1005Metric016
JST_SM02B_GHS_TB
R_0402_1005Metric012
R_0402_1005Metric014
C_0603_1608Metric002
R_0402_1005Metric016
SOT-323_SC-70
R_0402_1005Metric018
SOT-323_SC-002
R_0402_1005Metric020
C_0402_1005Metric018
R_0402_1005Metric022
C_0402_1005Metric020
C_0402_1005Metric022
VSSOP-8_3x3mm_P0.65mm002
R_0402_1005Metric024
C_0402_1005Metric024
SOT-323_SC-004
R_0402_1005Metric026
R_0402_1005Metric028
R_0402_1005Metric030
R_0402_1005Metric032
SOT-323_SC-006
C_0402_1005Metric026
C_0603_1608Metric004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

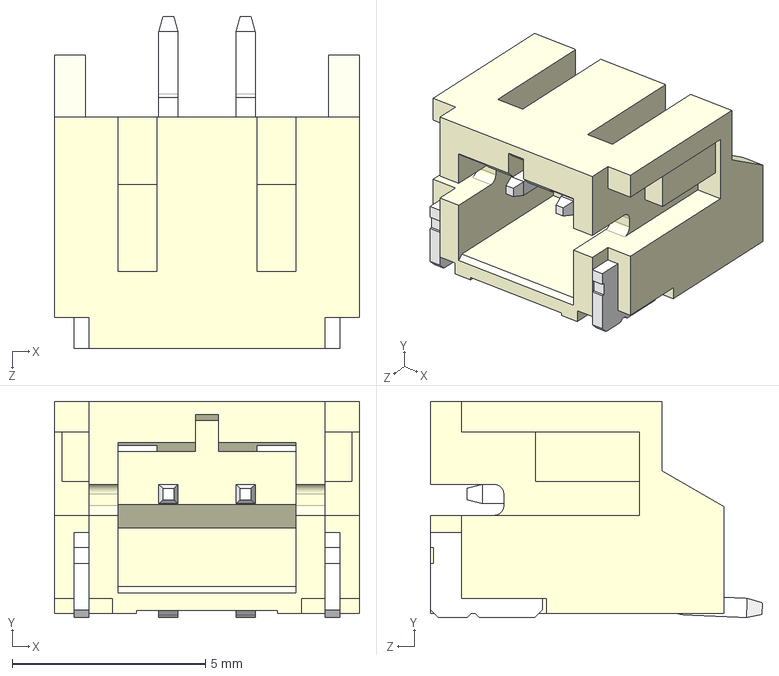
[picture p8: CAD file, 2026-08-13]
electronics/floating_hub_2_sided/models/S2B-PH-SM4-TB.step
7.90 x 5.60 x 8.60 mm

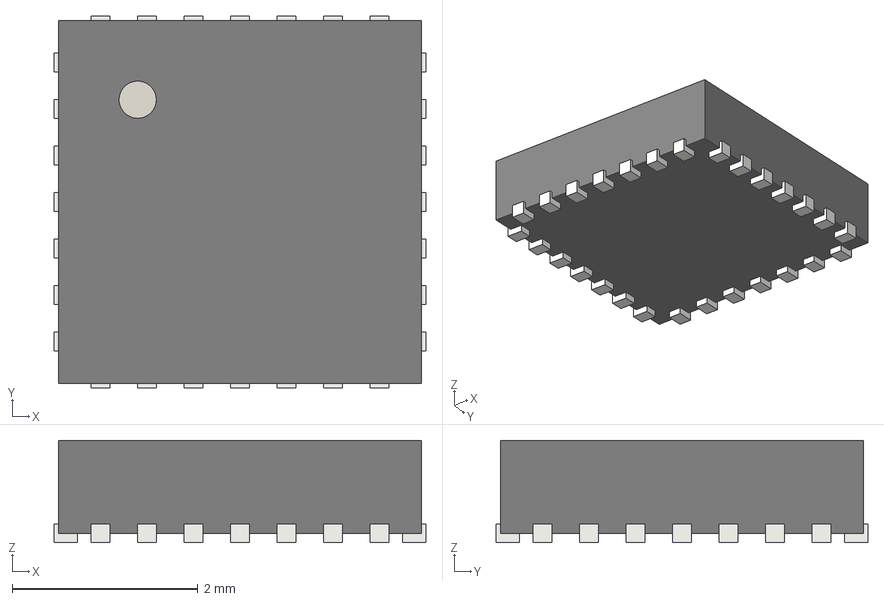
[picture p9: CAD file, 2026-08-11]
electronics/reward_port_2_sided/kicad/3d_models/QFN-28_4x4mm_P0.5mm.step
4.00 x 4.00 x 1.10 mm

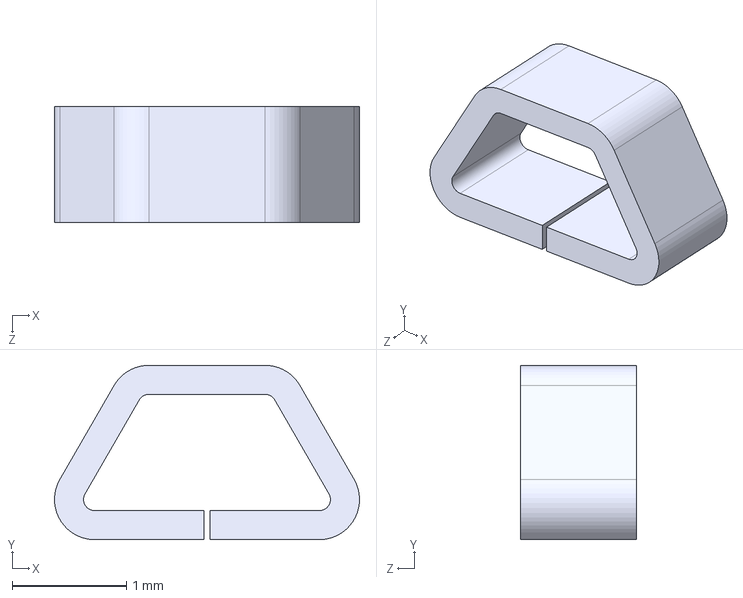
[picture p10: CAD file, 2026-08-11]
electronics/floating_hub/models/5015.step
2.67 x 1.52 x 1.02 mm

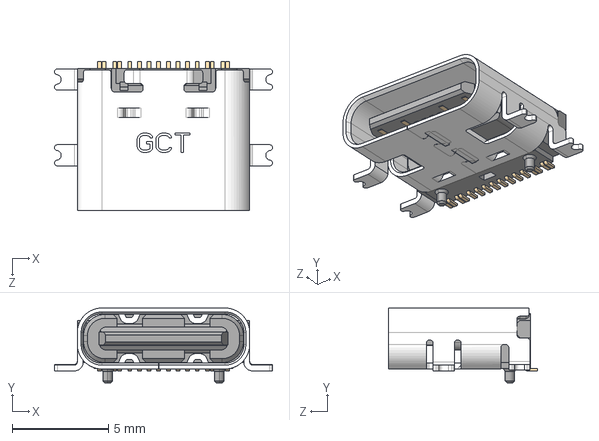
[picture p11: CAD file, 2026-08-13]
electronics/floating_hub_2_sided/models/USB4110GFA--3DModel-STEP-269445.STEP
11.3 x 3.89 x 7.70 mm

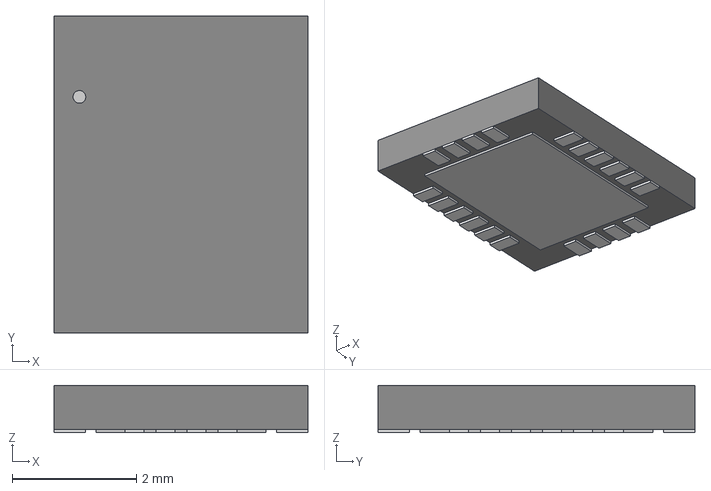
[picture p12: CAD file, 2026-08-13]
electronics/head_sensor/models/UFD_05-08-1711_ADI.step
4.09 x 5.11 x 0.765 mm

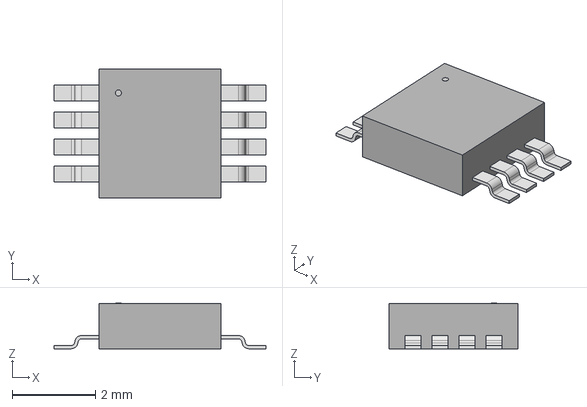
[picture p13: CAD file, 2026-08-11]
electronics/reward_port_2_sided/kicad/3d_models/PAM8302AASCR_DIO.step
5.10 x 3.10 x 1.09 mm

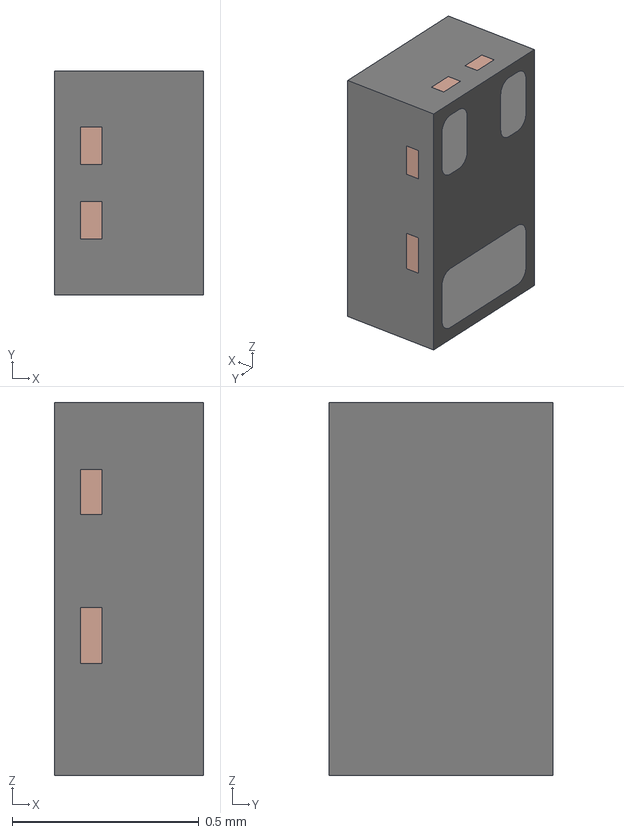
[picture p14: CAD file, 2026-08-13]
electronics/head_sensor/models/DFN1006H4-3.stp
0.4 x 0.6 x 1.00 mm
LDF_0

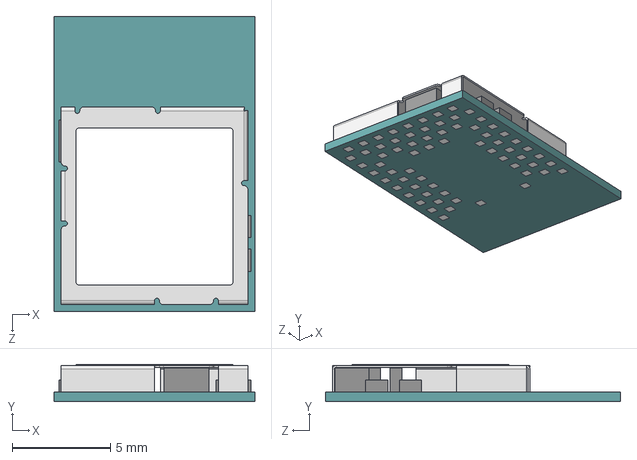
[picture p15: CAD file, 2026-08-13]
electronics/floating_hub_2_sided/models/BMD-340-A-R--3DModel-STEP-56544.STEP
10.2 x 1.90 x 15.0 mm

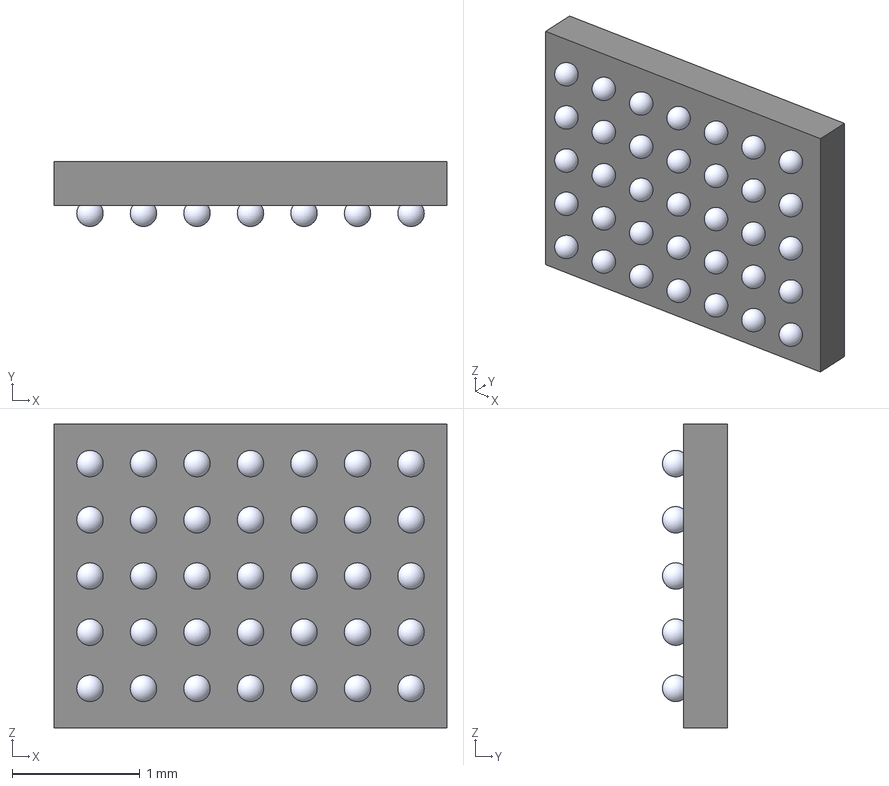
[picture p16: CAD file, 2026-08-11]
electronics/floating_hub_2_sided/models/NPM1300-CAAA-R--3DModel-STEP-510211.STEP
3.08 x 0.51 x 2.38 mm
Body_Solid1
Body002_Solid1
BALL_0001
BALL_0002
BALL_0003
BALL_0004
BALL_0005
BALL_0006
BALL_0007
BALL_0008
BALL_0009
BALL_0010
BALL_0011
BALL_0012
BALL_0013
BALL_0014
BALL_0015
BALL_0016
BALL_0017
BALL_0018
BALL_0019
BALL_0020
BALL_0021
BALL_0022
BALL_0023
BALL_0024
BALL_0025
BALL_0026
BALL_0027
BALL_0028
BALL_0029
BALL_0030
BALL_0031
BALL_0032
BALL_0033
BALL_0034
BALL_0035

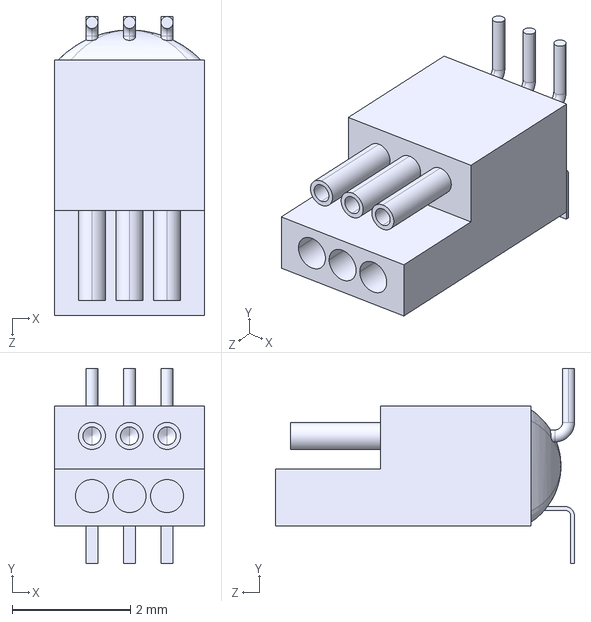
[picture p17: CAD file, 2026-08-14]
electronics/head_sensor/models/A79607-001.STEP
2.54 x 3.30 x 5.05 mm

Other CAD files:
electronics/floating_hub_2_sided/models/5015.step
electronics/floating_hub/models/BMD-340-A-R--3DModel-STEP-56544.STEP
electronics/reward_port/3d_models/QFN-28_4x4mm_P0.5mm.step
electronics/reward_port/3d_models/PAM8302AASCR_DIO.step
electronics/floating_hub/models/USB4110GFA--3DModel-STEP-269445.STEP
electronics/floating_hub/models/S2B-PH-SM4-TB.step

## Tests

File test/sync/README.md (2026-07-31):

# Korora synchronization system

## Purpose

This repository implements a four node timing experiment for measuring clock conversion quality, external event alignment, scheduled TTL generation, and command latency.

The system uses Korora as the reference time domain. Fairy and Galapagos maintain independent affine clock models that convert their local timestamps into Korora timer ticks. Adelie is a laptop client that measures application level clock exchange quality and command round trip latency through Bluetooth.

The current implementation targets nRF Connect SDK 3.4.0 for the Nordic boards and STM32 HAL with PlatformIO for Fairy.

## Nodes

### Korora

Korora runs on an nRF52840 DK using the board target:

```text
nrf52840dk/nrf52840
```

Korora is the reference node.

Its responsibilities are:

- Run the 16 MHz reference timer
- Emit the Fairy synchronization pulse
- Poll Fairy over I2C
- Connect to Galapagos as a Bluetooth central
- Advertise an Adelie control service as a Bluetooth peripheral
- Build one independent affine model for Fairy
- Build one independent affine model for Galapagos
- Capture the shared external event locally in hardware
- Convert remote event timestamps into Korora time
- Match remote events to the nearest Korora reference event
- Schedule hardware TTL pulses on Galapagos
- Capture the returned Galapagos TTL pulse on P1.12 using GPIOTE, PPI, and TIMER3
- Stream versioned CSV records over the virtual serial port

### Fairy

Fairy runs on an STM32 Nucleo G071RB.

Its responsibilities are:

- Capture the Korora synchronization pulse with TIM2
- Capture the shared external event with TIM2
- Extend the local timer into a 64 bit time value
- Queue synchronization, event, and command acknowledgement records
- Return one atomic 40 byte frame per I2C read
- Receive immediate command bytes from Korora
- Report status and fault counters

Fairy is an I2C target at unshifted address `0x42`.

### Galapagos

Galapagos runs on an nRF54L15 DK using the board target:

```text
nrf54l15dk/nrf54l15/cpuapp
```

Galapagos advertises as:

```text
galapagos
```

Its responsibilities are:

- Report selected Bluetooth connection anchor timestamps
- Capture the shared external event on P1.11
- Use GPIOTE, DPPI, and GRTC for hardware event capture
- Receive scheduled TTL commands from Korora
- Generate a hardware timed TTL pulse on P1.12 using GRTC compare events, DPPI, and GPIOTE SET and CLR tasks
- Report the local timestamp associated with the generated TTL edge
- Queue outgoing 40 byte records
- Send one Bluetooth notification at a time
- Preserve a nominal 16 MHz timestamp domain by multiplying GRTC microseconds by 16

The current Galapagos report rate is approximately 1 Hz.

### Adelie

Adelie is the laptop client.

Its responsibilities are:

- Connect to the Korora Adelie service
- Perform repeated application clock exchanges
- Fit a rolling 16 point Adelie to Korora clock model
- Send immediate Fairy commands through Korora
- Record command stage notifications
- Save clock and latency CSV files
- Produce host side summaries

## Main timing domains

Korora uses a 16 MHz timer as the common reference domain.

Fairy reports local TIM2 ticks at 16 MHz.

Galapagos receives GRTC timestamps at 1 MHz and multiplies them by 16 before transmission. Bluetooth anchor timestamps and scheduled TTL timestamps are represented in the same nominal 16 MHz domain.

Adelie uses host monotonic nanoseconds at 1 GHz.

The stream identifies each timestamp frequency explicitly for normal event rows.

## Clock model

Each embedded remote node has an independent 16 point affine model.

The reference point form reduces numerical loss when timestamps become large.

The model has two operating states:

- `ACQUIRE` means there are not yet enough accepted points or the model was reset
- `TRACK` means the current model passed admission checks and can convert timestamps

A model reset begins a new analysis segment. Fits and interval calculations must not cross a reset boundary.

## Hardware synchronization paths

### Fairy synchronization path

Korora emits a periodic pulse using TIMER2, PPI, and GPIOTE.

The nominal current rate is 4 Hz.

The pulse path is:

```text
Korora TIMER2 compare
→ PPI
→ GPIOTE output task
→ Fairy TIM2 input capture
```

Korora associates a returned Fairy synchronization record with its own pulse schedule. Fairy does not need to assign the Korora pulse number.

### Galapagos synchronization path

Korora and Galapagos both observe Bluetooth connection event anchors from their controllers.

Galapagos sends selected anchor reports to Korora in the shared 40 byte frame. Korora matches the Bluetooth event counter and maps the controller anchor into the Korora timer domain.

Galapagos currently sends approximately one selected anchor report per second.

### Scheduled Galapagos TTL path

Korora periodically chooses a target time in the Korora domain and uses the current Galapagos affine model to calculate the corresponding Galapagos local target.

Korora sends a 20 byte scheduling command over the Galapagos TTL control characteristic. Galapagos uses two absolute GRTC compare events to generate the rising and falling edges entirely in hardware.

The output path is:

```text
Galapagos GRTC SET compare
→ DPPI connection
→ GPIOTE SET task
→ Galapagos P1.12 rising edge
→ Korora P1.12 input
→ GPIOTE event
→ PPI connection
→ Korora TIMER3 capture
```

A second GRTC compare triggers the Galapagos GPIOTE CLR task at the requested pulse width.

Korora TIMER3 is cleared from the same TIMER2 compare event that begins each 4 Hz reference interval. This keeps TIMER3 phase aligned with TIMER2 while leaving the existing TIMER2 capture channels unchanged.

The standard automated test currently uses:

```text
lead time 300 ms
period 1000 ms
pulse width 100 us
timeout 250 ms after the target
```

Korora logs the scheduled target, the generated timestamp reported by Galapagos, the locally acquired edge, and the combined result.

## External event capture

A shared rising edge should be wired to the event input on each participating embedded node.

Korora uses hardware capture into TIMER2.

Fairy uses TIM2 input capture.

Galapagos uses:

```text
P1.11 rising edge
→ GPIOTE event
→ DPPI connection
→ GRTC capture task
→ GRTC compare register
```

The Galapagos interrupt handler reads the already captured register value. Interrupt latency is not part of the event timestamp.

The Galapagos overlay assigns the Zephyr user event GPIO property to GPIO controller 1 pin 11 with active high polarity.

## Suggested wiring

### Korora and Fairy

- Korora I2C SCL on P0.27 to Fairy PB8
- Korora I2C SDA on P0.26 to Fairy PB9
- Korora synchronization output on P1.10 to Fairy PA0
- Shared external event to Korora P1.11
- Shared external event to Fairy PA1
- Common ground between boards

Use one suitable pair of I2C pull resistors to the correct application voltage.

Do not connect independently powered USB board power rails together.

### Galapagos event input

- Shared external event to Galapagos P1.11
- Common ground with the event generator and the other boards

Verify that the event source uses safe logic levels for every connected board.

### Galapagos scheduled TTL output

- Galapagos P1.12 to Korora P1.12
- Galapagos ground to Korora ground
- Keep the P1.11 shared external event wiring separate from the P1.12 scheduled TTL wiring

The current direct digital connection assumes that Galapagos produces a 3.3 V compatible high level for Korora. Do not connect the two board power rails together when both boards are independently USB powered.

## Repository layout

```text
korora/
    src/
        main.c
        adelie_protocol.h
    boards/
        nrf52840dk_nrf52840.overlay
    prj.conf

fairy/
    src/
        main.c
    platformio.ini

galapagos/
    src/
        main.c
    boards/
        nrf54l15dk_nrf54l15_cpuapp.overlay
    prj.conf

adelie/
    adelie.py
    requirements.txt

analysis/
    parse_sync_log.py
    analyse_sync.py
    plot_sync.py
    run_all.py

README.md
PROTOCOL.md
```

Repository also includes `arduino_pulse` which is the GPIO event generator made from an `arduino due` on PlatformIO.

## Bring up order

1. Flash Fairy and connect the I2C wiring

2. Flash Galapagos and confirm that it advertises

3. Flash Korora

4. Open Korora VCOM0 at 115200 baud using 8 data bits, no parity, and 1 stop bit

5. Confirm that Korora prints `SCHEMA,3`

6. Confirm that Korora prints its `READY` record and `TTL_INPUT_READY`

7. Confirm that the Fairy link produces `PAIR_RAW` and `SYNC` records

8. Confirm that the Galapagos link reaches connected and subscribed states

9. Wait for both remote clock models to reach `TRACK`

10. Confirm that the scheduled TTL test produces `TTL_PULSE_SCHEDULED`, `TTL_PULSE_GENERATED`, `TTL_PULSE_ACQUIRED`, and `TTL_PULSE_RESULT`

11. Start Adelie and confirm clock replies and command stage notifications

12. Apply a shared GPIO pulse and confirm Korora, Fairy, and Galapagos event records

13. Record the Korora serial stream for analysis

## Expected startup records

A healthy Korora stream begins with:

```text
SCHEMA,3
```

It then prints schema comments and a `READY` row.

The Korora TTL input should report:

```text
TTL_INPUT_READY,korora,pin=44,timer=3,cc=0
TTL_TEST_CONFIG,lead_ms=300,period_ms=1000,width_us=100,ttl_input_pin=44
```

Typical link activity includes:

```text
LINK,galapagos,BLE,CENTRAL,SCANNING,galapagos,0,0
LINK,galapagos,BLE,CENTRAL,CONNECTED,galapagos,10000,0
LINK,galapagos,BLE,CENTRAL,SUBSCRIBED,galapagos,10000,0
```

Exact reason and interval values depend on the current firmware.

Galapagos should report:

```text
EVENT_CAPTURE_READY,galapagos,pin=43,gpiote_ch=0,grtc_ch=0
TTL_OUTPUT_READY,galapagos,pin=44,gpiote_ch=1,set_grtc_ch=1,clear_grtc_ch=2
BLE_ADVERTISING,galapagos
READY,galapagos,1,40,HARDWARE_CAPTURE,event_pin=43,ttl_output_pin=44,grtc_ch=0
```

Channel values are allocated at runtime and can differ.

## Serial recording

Korora normally appears as VCOM0 through the debugger interface.

Use:

```text
115200 baud
8 data bits
no parity
1 stop bit
no software flow control
no hardware flow control
```

Python script `serial_record.py` does a good job of that.

## Analysis workflow

The analysis pipeline has three main stages.

### Parse

`parse_sync_log.py` reads the Korora serial stream and the Adelie CSV files.

It produces normalized CSV files for pairs, synchronization rows, events, matches, diagnostics, links, faults, scheduled TTL records, and Adelie measurements.

### Analyse

`analyse_sync.py` derives:

- Adjacent interval clock error in ppm
- Firmware slope error in ppm
- Firmware RMS in microseconds
- Independent rolling fit RMS
- Model resets and rejected fits
- Event signed error
- Event absolute error
- Event transport age
- Event matching counts
- Scheduled TTL generation error
- Scheduled TTL acquisition error
- Galapagos generated to Korora acquired offset
- Scheduled TTL completion and timeout counts
- Adelie clock exchange RTT
- Adelie rolling model quality
- Command stage latency
- End to end command RTT

The node summaries and scheduled TTL path are written into one integrated `summary.csv` and `summary.txt`.

### Plot

`plot_sync.py` produces selected diagnostic plots.

Useful plot groups include:

- Clock rate variation
- Firmware and rolling RMS
- Model residuals
- External event error
- Event error distribution
- Event error compared with transport age
- Scheduled TTL error components
- Scheduled TTL total error distribution
- Scheduled TTL success and timeout outcomes
- Adelie network RTT
- Adelie model prediction error
- Command latency breakdown

## Interpretation notes

A positive adjacent interval error means the remote clock accumulated more nominal time than Korora during that interval.

The firmware slope often has the opposite sign because it maps the faster remote clock back into the Korora domain.

Firmware RMS describes scatter of the points inside the active model window.

One step prediction error evaluates how well the previous model predicts the next point.

Event signed error can have a median near zero even when the absolute error is large. Positive and negative errors cancel in the signed statistic.

Transport age is not the synchronization error. It describes how old the captured event was when it was reported.

For the scheduled TTL path:

```text
generation error = converted Galapagos generated time minus target Korora time
wire offset = Korora acquired time minus converted Galapagos generated time
total error = Korora acquired time minus target Korora time
```

`total_error_ns` is the main end to end result. `wire_offset_ns` contains fixed hardware path delay, signal threshold delay, timer reconstruction error, and remaining Galapagos to Korora clock model error. A negative value does not mean that electrical propagation occurred backwards in time.

Adelie one way latency values are estimates because they depend on a noisy host to Korora clock model and on path symmetry assumptions. End to end command RTT is the strongest Adelie latency measurement.

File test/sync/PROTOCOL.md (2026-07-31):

# Synchronization and command protocol

## Scope

This document defines the current communication and logging interfaces between Korora, Fairy, Galapagos, and Adelie.

It covers:

- The shared 40 byte remote record frame
- Fairy I2C transactions
- Galapagos Bluetooth notifications
- Korora to Galapagos scheduled TTL commands
- Adelie 20 byte control frames
- Korora stream schema version 3
- Clock model and event matching rules
- Concurrency and data integrity requirements

All numeric wire fields use little endian byte order unless stated otherwise.

## Public node names

The canonical names are:

```text
korora
fairy
galapagos
adelie
```

Older logs may contain `reward_port`. Parsers provided normalize that legacy name to `fairy`.

## Shared remote frame

Fairy and Galapagos use the same 40 byte frame format.

Frame constants:

```text
magic 0xA5
version 2
length 40
```

### Byte layout

Offset 0

Size 1

Field `magic`

Required value `0xA5`

Offset 1

Size 1

Field `version`

Required value `2`

Offset 2

Size 1

Field `status_flags`

Offset 3

Size 1

Field `length`

Required value `40`

Offset 4

Size 1

Field `record_type`

Offset 5

Size 1

Field `pending_count`

Offset 6

Size 1

Field `record_flags`

Offset 7

Size 1

Field `reserved`

Required value `0`

Offset 8

Size 8

Field `capture_ticks`

Offset 16

Size 8

Field `snapshot_ticks`

Offset 24

Size 4

Field `capture_loss_count`

Offset 28

Size 4

Field `transport_error_count`

Offset 32

Size 4

Field `auxiliary`

Offset 36

Size 2

Field `crc`

Offset 38

Size 2

Field `reserved_tail`

Required value `0`

### CRC

The CRC is CRC 16 CCITT with polynomial `0x1021` and initial value `0xFFFF`.

The CRC covers bytes 0 through 35.

The CRC field itself and the final reserved bytes are not included.

A receiver must reject a frame when any of these checks fail:

- Magic is not `0xA5`
- Version is not `2`
- Length is not `40`
- CRC does not match
- Reserved values violate the current version rules

## Status flags

Bit 0

Name `RECORD_VALID`

Meaning a record is present

Bit 1

Name `FIRST_AFTER_RESET`

Meaning this is the first valid report after reset or connection state reset

Bit 2

Name `CAPTURE_LOSS_LATCHED`

Meaning a hardware overcapture, queue overflow, or dropped report was observed

Bit 3

Name `TRANSPORT_ERROR_LATCHED`

Meaning an I2C or Bluetooth transport error was observed

Bit 4

Name `CLOCK_FAULT`

Meaning the source clock or capture path entered a fault state

Bits 5 through 7 are reserved.

## Record flags

Bit 0 is currently used by Fairy to report hardware overcapture for the associated timer channel.

Galapagos currently sends zero record flags.

All unknown record flag bits must be preserved in raw logs and ignored by older receivers unless the protocol version changes their meaning.

## Record types

Value `0`

Name `NONE`

Meaning no record

Value `1`

Name `SYNC`

Meaning synchronization observation

Value `2`

Name `EVENT`

Meaning external GPIO event

Value `3`

Name `COMMAND_ACK`

Meaning Fairy command acknowledgement

Value `4`

Name `TTL_GENERATED`

Meaning Galapagos generated a scheduled TTL rising edge

## Common timestamp fields

### capture_ticks

This is the source timestamp associated with the record.

For Fairy it is a 64 bit TIM2 timestamp in a 16 MHz domain.

For a Galapagos synchronization record it is the selected Bluetooth anchor timestamp multiplied by 16.

For a Galapagos event record it is the GRTC hardware capture timestamp multiplied by 16.

For a Galapagos TTL generated record it is the programmed GRTC SET compare timestamp multiplied by 16.

### snapshot_ticks

This is the source clock value when the frame was built or the record snapshot was created.

The source transport age is the difference between snapshot ticks and capture ticks.

For a modulo free 64 bit counter this requires snapshot ticks to be at or after capture ticks.

The receiver must treat impossible ordering as a malformed or stale frame.

### capture_loss_count

This is a cumulative source counter.

Fairy increments it for timer overcapture or FIFO overflow.

Galapagos increments it when a report cannot be queued or is discarded because the link is unavailable.

### transport_error_count

This is a cumulative source counter.

Fairy uses it for non address failure I2C errors.

Galapagos uses it for Bluetooth notification failures and related transport failures.

### pending_count

This is queue occupancy associated with the returned or transmitted record.

It is not a synchronization ID.

It is not an event ID.

It must not be used for matching.

## Auxiliary field

The 32 bit auxiliary field depends on source and record type.

### Fairy synchronization and event records

Existing Fairy firmware may place boot reset status or another source diagnostic value here.

Korora must not assume that this field is an event sequence unless the Fairy firmware version explicitly defines it.

Current Korora analysis may assign a synthetic increasing event ID to Fairy event records.

### Fairy command acknowledgement

The command token is carried in the low seven bits.

The acknowledgement must match the active command token in Korora.

### Galapagos synchronization record

The low 16 bits contain the Bluetooth connection event counter.

Korora unwraps and matches this counter to its own controller anchor observation.

### Galapagos event record

The field contains the Galapagos external event sequence.

The sequence increases once for each accepted GPIO capture.

### Galapagos TTL generated record

The field contains the Korora assigned TTL test sequence.

Korora uses this sequence to associate the returned generated timestamp with the active scheduled pulse.

## Fairy I2C transport

Korora is the I2C controller.

Fairy is the target at unshifted address:

```text
0x42
```

### Read transaction

Korora reads exactly 40 bytes.

Fairy presents one atomic snapshot of the oldest queued record.

A complete successful target transmit removes that record from the queue.

An aborted transfer leaves the record queued for retry.

Korora validates magic, version, length, reserved values, and CRC before using the frame.

### Fairy FIFO

The current Fairy FIFO contains 16 records.

Synchronization, event, and command acknowledgement records share the transport.

Queue overflow increments the capture loss count and can latch a clock fault.

### Fairy synchronization pairing

Fairy does not need to know the Korora pulse number.

Korora assigns the pulse identity using its own hardware pulse schedule and the acceptance window.

The pairing process is:

1. Korora emits a hardware synchronization pulse

2. Fairy captures the edge

3. Korora polls Fairy

4. Korora checks frame integrity

5. Korora checks transport age and pulse phase

6. Korora holds at most one valid candidate for the pulse window

7. Korora admits the candidate after the window closes

8. Korora sends the accepted pair to the Fairy clock model

A second valid synchronization candidate in the same acceptance window invalidates that window.

A stale synchronization record is drained and reported but is not assigned to a new pulse.

Event and command acknowledgement records are handled independently from synchronization admission.

### Fairy command bytes

Value `0x01`

Meaning acknowledge the first after reset status

Value `0x02`

Meaning clear latched capture and transport status flags while preserving cumulative counters

Values with bit 7 set

Meaning execute the immediate command

For an immediate command:

```text
command byte equals 0x80 combined with token
```

The token uses the low seven bits.

Example:

```text
sequence 10000
token 16
command byte 0x90
```

Fairy records command receipt, executes the action in thread context, and queues a command acknowledgement record.

The action must not run inside the I2C interrupt callback.

## Galapagos Bluetooth transport

Galapagos is a Bluetooth peripheral.

Korora is the Bluetooth central for this link.

The advertised name is:

```text
galapagos
```

### Service UUID values

The synchronization service uses the encoded value:

```text
A88278D0 7009 4BEE A6F8 E1DC3FF02B92
```

The scheduled TTL control characteristic uses:

```text
A88278D1 7009 4BEE A6F8 E1DC3FF02B92
```

The anchor report characteristic uses:

```text
A88278D2 7009 4BEE A6F8 E1DC3FF02B92
```

The TTL control characteristic accepts writes without response. The anchor report characteristic supports notifications.

### Notification payload

Each notification contains exactly one 40 byte shared remote frame.

Galapagos sends synchronization, external event, and TTL generated records through one outgoing queue.

The notification path must permit only one active notification at a time.

The required design is:

```text
record producer
→ outgoing message queue
→ notification thread
→ bt_gatt_notify_cb
→ completion callback
→ next record
```

The frame buffer must remain valid until notification completion.

Temporary memory exhaustion or retry conditions may be retried after a short delay.

A disconnect or disabled notification state should purge stale queued records.

### Galapagos anchor report

The SoftDevice Controller provides:

- Connection handle
- Connection event counter
- Anchor timestamp in microseconds

Galapagos selects reports according to the configured report cadence.

The current target report rate is approximately 1 Hz.

The transmitted local timestamp is the anchor microsecond value multiplied by 16.

The connection event counter is placed in the low 16 bits of the auxiliary field.

### Galapagos hardware event capture

The overlay defines P1.11 as the event input.

The capture path is:

```text
GPIO rising edge
→ GPIOTE input event
→ DPPI or GPPI connection
→ GRTC capture task
→ GRTC compare register
```

GRTC runs at 1 MHz.

The interrupt handler reads the already captured compare value and queues a record.

The transmitted local timestamp is the captured microsecond value multiplied by 16.

The interrupt handler must not use a mutex, wait for Bluetooth, or perform serial logging.

## Korora to Galapagos scheduled TTL command

Korora and Galapagos use a separate 20 byte little endian frame for scheduled TTL commands.

This frame is independent from the Adelie 20 byte control frame and uses different magic and field meanings.

Frame constants:

```text
magic 0x544C
version 1
length 20
```

### Byte layout

Offset 0

Size 2

Field `magic`

Required value `0x544C`

Offset 2

Size 1

Field `version`

Required value `1`

Offset 3

Size 1

Field `opcode`

Value `1` means schedule one TTL pulse

Offset 4

Size 4

Field `sequence`

Offset 8

Size 8

Field `target_ticks`

Offset 16

Size 4

Field `pulse_width_us`

### Command validation

Galapagos must reject a command when:

- The frame length is not 20 bytes
- The magic is not `0x544C`
- The version is not `1`
- The opcode is not `1`
- Another pulse is already armed
- The target is less than the configured minimum lead time in the future
- The requested width is zero or greater than the configured maximum

The current minimum lead time is 50000 microseconds.

The current maximum accepted pulse width is 100000 microseconds.

### Galapagos TTL generation

The TTL output is P1.12.

The rising edge path is:

```text
GRTC absolute SET compare
→ DPPI or GPPI connection
→ GPIOTE SET task
→ P1.12 high
```

The falling edge path is:

```text
GRTC absolute CLR compare
→ DPPI or GPPI connection
→ GPIOTE CLR task
→ P1.12 low
```

The CLR compare is programmed at the target time plus `pulse_width_us`.

The physical rising edge is generated by hardware and does not wait for the compare interrupt callback.

When the SET compare occurs, Galapagos queues a shared remote frame with record type `TTL_GENERATED`.

For that frame:

- `capture_ticks` is the scheduled SET compare timestamp multiplied by 16
- `snapshot_ticks` is the local timestamp when the report snapshot is created
- `auxiliary` is the TTL sequence from the scheduling command

### Korora TTL acquisition

Galapagos P1.12 is wired to Korora P1.12 with a common ground.

Korora captures the returned rising edge through:

```text
Korora P1.12 rising edge
→ GPIOTE input event
→ PPI or GPPI connection
→ TIMER3 CAPTURE0
```

TIMER3 is cleared from the same TIMER2 COMPARE0 event that begins each 4 Hz reference interval. Korora combines the captured TIMER3 phase with the current TIMER2 period count to reconstruct a 64 bit Korora timestamp.

The current direct digital connection assumes a Galapagos output voltage compatible with the Korora input threshold.

The standard automated test uses a 300 millisecond lead time, a 1000 millisecond period, and a 100 microsecond pulse width.

## Adelie control frame

Adelie and Korora use a separate 20 byte application frame.

Frame constants:

```text
magic 0xAD1E
version 1
length 20
```

### Byte layout

Offset 0

Size 2

Field `magic`

Offset 2

Size 1

Field `version`

Offset 3

Size 1

Field `message_type`

Offset 4

Size 4

Field `sequence`

Offset 8

Size 8

Field `timestamp`

Offset 16

Size 4

Field `value`

All fields use little endian order.

The frame fits inside one ATT operation at the default ATT MTU.

## Adelie request types

Value `0x01`

Name `CLOCK_SYNC_REQUEST`

Meaning request one Korora clock exchange reply

Value `0x02`

Name `FAIRY_DO_NOW_REQUEST`

Meaning execute an immediate Fairy command

## Adelie notification types

Value `0x81`

Name `CLOCK_REPLY`

Timestamp meaning Korora receive time

Value meaning Korora reply queue time difference from receive time

Value `0x90`

Name `COMMAND_KORORA_RX`

Meaning Korora received the Adelie command

Value `0x91`

Name `COMMAND_FAIRY_TX_START`

Meaning Korora started the Fairy I2C command transfer

Value `0x92`

Name `COMMAND_FAIRY_RX`

Meaning Fairy received the command

Value `0x93`

Name `COMMAND_FAIRY_EXEC`

Meaning Fairy completed the immediate action timestamp

Value `0x94`

Name `COMMAND_KORORA_ACK_RX`

Meaning Korora received the Fairy acknowledgement

Value `0x95`

Name `COMMAND_KORORA_DONE_TX`

Meaning Korora queued or submitted the final result notification

Value `0xFF`

Name `ERROR`

Meaning the request failed

## Adelie status values

Value `0`

Name `OK`

Value `1`

Name `BUSY`

Value `2`

Name `BAD_FRAME`

Value `3`

Name `I2C_WRITE_FAILED`

Value `4`

Name `TIMEOUT`

Value `5`

Name `FAIRY_MODEL_INVALID`

Value `6`

Name `TOKEN_MISMATCH`

Value `7`

Name `NOTIFY_FAILED`

## Adelie clock exchange

Adelie records four logical timestamps.

`t1`

Adelie time immediately before the write

`t2`

Korora time in the receive callback

`t3`

Korora time immediately before the reply is queued

`t4`

Adelie time in the notification callback

The network round trip is the full Adelie elapsed interval after removing Korora processing time.

The clock pair uses the midpoint of the Adelie interval and the midpoint of the Korora interval.

The rolling model uses the latest 16 accepted exchanges.

The current application performs repeated exchanges in the background and refits after each accepted point.

One way latency values are estimates because they depend on the fitted model and path symmetry.

## Adelie command sequence

A normal command progresses through:

1. Adelie command transmit

2. Korora command receive

3. Korora Fairy transfer start

4. Fairy command receive

5. Fairy command action complete

6. Korora acknowledgement receive

7. Korora result queue

8. Korora result transmit submission

9. Adelie result receive

The final end to end round trip uses Adelie send time and Adelie receive time.

Internal stage times use Korora and Fairy hardware timestamp domains after conversion where required.

The 0x95 timestamp is the Korora result queue or submission time. It is not guaranteed to be the physical Bluetooth radio transmit start.

## Korora stream schema version 3

Korora begins the machine readable stream with:

```text
SCHEMA,3
```

A parser must switch explicitly on the schema version.

A parser must not guess a column layout after an unsupported schema value.

Every machine readable record is CSV.

For node qualified records, the second field is the node name.

## PAIR_RAW record

Format:

```text
PAIR_RAW,node,sync_id,hub_ticks,local_ticks,prospective_count,has_previous,local_delta_ticks,local_interval_error_ticks,transport_age_ticks
```

Field meanings:

`node`

Remote node name

`sync_id`

Fairy pulse number or unwrapped Galapagos connection event counter

`hub_ticks`

Korora timestamp associated with the pair

`local_ticks`

Remote timestamp

`prospective_count`

Number of samples that would exist after admitting this point

`has_previous`

One when an adjacent previous pair is available

`local_delta_ticks`

Local interval since the previous accepted pair

`local_interval_error_ticks`

Difference between measured local interval and the nominal interval

`transport_age_ticks`

Age reported by the source frame

## SYNC record

Format:

```text
SYNC,node,sync_id,hub_ticks,local_ticks,status_flags,record_flags,pending_count,state,slope_ppb,local_reference_ticks,hub_reference_ticks,rms_ns,prefit_residual_ns,model_step_ns,transport_age_ticks
```

Field meanings:

`status_flags`

Raw remote status flags

`record_flags`

Raw per record flags

`pending_count`

Remote queue occupancy

`state`

`ACQUIRE` or `TRACK`

`slope_ppb`

Affine slope error in parts per billion

`local_reference_ticks`

Local reference point for the affine model

`hub_reference_ticks`

Korora value at the reference point

`rms_ns`

Current model residual RMS

`prefit_residual_ns`

Residual of the new point before refitting

`model_step_ns`

Change in model prediction produced by the proposed update

## EVENT record

Format:

```text
EVENT,node,event_id,kind,local_ticks,local_hz,hub_ticks,state,transport_age_ticks
```

Field meanings:

`event_id`

Identity assigned by the source or by Korora

`kind`

Event stage name

`local_ticks`

Timestamp in the node local domain

`local_hz`

Frequency of the local timestamp domain

`hub_ticks`

Timestamp expressed in Korora time when available

`state`

Conversion state

`transport_age_ticks`

Age in the source local domain

### Event states

`LOCAL`

The timestamp is already in Korora time

`TRACK`

A valid model converted the timestamp into Korora time

`UNSYNC`

No valid model was available

`REMOTE`

Korora received the timestamp but does not own the source conversion model

For `UNSYNC`, the hub timestamp sentinel is outside the valid time range and must not be plotted as a real timestamp.

### Event kinds

Current kinds include:

- `GPIO_RISE`
- `CLOCK_SYNC_TX`
- `CLOCK_SYNC_RX`
- `CLOCK_SYNC_REPLY_QUEUE`
- `CLOCK_SYNC_REPLY_TX`
- `COMMAND_TX`
- `COMMAND_RX`
- `COMMAND_FORWARD`
- `COMMAND_EXEC`
- `COMMAND_ACK_RX`
- `COMMAND_RESULT_QUEUE`
- `COMMAND_RESULT_TX`

## EVENT_MATCH record

Format:

```text
EVENT_MATCH,node,event_id,reference_node,reference_event_id,converted_hub_ticks,reference_hub_ticks,error_ns
```

Korora emits this after matching a converted remote GPIO event to a cached Korora GPIO event.

The signed error is the converted remote event time relative to the Korora reference time.

A positive error means the converted remote event is later than the Korora reference event.

A match is valid only when:

- The remote model is in `TRACK`
- The converted timestamp is valid
- A Korora reference event exists inside the configured match window
- The reference event ID is greater than zero

Zero reference IDs are invalid sentinels and must not be included in matched event plots.

## TTL_PULSE_SCHEDULED record

Format:

```text
TTL_PULSE_SCHEDULED,node,sequence,target_hub_ticks,target_galapagos_ticks,pulse_width_us
```

Korora emits this after it has converted the selected Korora target into the Galapagos local domain and successfully submitted the scheduling write.

## TTL_PULSE_GENERATED record

Format:

```text
TTL_PULSE_GENERATED,node,sequence,generated_local_ticks,generated_hub_ticks,target_hub_ticks,generation_error_ns
```

`generated_local_ticks` is the Galapagos GRTC SET compare timestamp in the nominal 16 MHz Galapagos domain.

`generated_hub_ticks` is that timestamp converted through the current Galapagos affine model.

The generation error is:

```text
generated_hub_ticks minus target_hub_ticks
```

## TTL_PULSE_ACQUIRED record

Format:

```text
TTL_PULSE_ACQUIRED,node,sequence,acquired_hub_ticks,target_hub_ticks,total_error_ns
```

`acquired_hub_ticks` is the Korora TIMER3 hardware capture reconstructed into the Korora 64 bit time domain.

The total error is:

```text
acquired_hub_ticks minus target_hub_ticks
```

## TTL_PULSE_RESULT record

Format:

```text
TTL_PULSE_RESULT,sequence,target_hub_ticks,target_galapagos_ticks,generated_hub_ticks,acquired_hub_ticks,generation_error_ns,wire_offset_ns,total_error_ns
```

The error definitions are:

```text
generation_error_ns = generated_hub_ticks minus target_hub_ticks
wire_offset_ns = acquired_hub_ticks minus generated_hub_ticks
total_error_ns = acquired_hub_ticks minus target_hub_ticks
```

Tick differences are converted from the 16 MHz Korora domain into nanoseconds.

`total_error_ns` is the main end to end scheduled TTL result.

`wire_offset_ns` includes the Galapagos output path, signal rise to the Korora input threshold, Korora input and capture delay, timer reconstruction effects, and remaining Galapagos to Korora clock model error. It is not a pure wire propagation measurement.

## TTL_PULSE_TIMEOUT record

Format:

```text
TTL_PULSE_TIMEOUT,sequence,target_hub_ticks,timeout_hub_ticks,generated_seen,acquired_seen
```

`generated_seen` is one when Korora received the Galapagos `TTL_GENERATED` report.

`acquired_seen` is one when Korora captured the returned physical rising edge.

A timeout can therefore distinguish a missing generated report from a missing physical acquisition.

## LINK record

Format:

```text
LINK,node,transport,role,state,peer,interval_us,reason
```

This describes connection and transport state.

Typical states include advertising, scanning, connected, disconnected, subscribed, and parameter updated.

## FAULT record

Format:

```text
FAULT,node,category,code,value
```

This reports failures and counters that require diagnostic attention.

The code may contain an operating system or transport error value.

## READY record

Format:

```text
READY,node,timer_hz,sync_period_ticks,fairy_i2c_address,model_window,max_skew_ppm,galapagos_name,event_pin
```

The current Korora implementation reports its key runtime configuration in this row.

Korora also reports the scheduled TTL input and test configuration with:

```text
TTL_INPUT_READY,korora,pin=44,timer=3,cc=0
TTL_TEST_CONFIG,lead_ms=300,period_ms=1000,width_us=100,ttl_input_pin=44
```

Galapagos reports the hardware TTL output allocation with:

```text
TTL_OUTPUT_READY,galapagos,pin=44,gpiote_ch=<allocated>,set_grtc_ch=<allocated>,clear_grtc_ch=<allocated>
```

GPIOTE and GRTC channel numbers are allocated at runtime and can differ between builds.

## Clock model rules

Each remote model uses a rolling window of 16 accepted pairs.

The model is affine and uses a local reference point.

A proposed point may be rejected because of:

- Invalid frame
- Invalid pulse or anchor identity
- Excess transport age
- Implausible adjacent interval
- Excess residual
- Excess RMS
- Excess model step
- Repeated admission rejection
- Capture or transport fault

A model reset invalidates timestamp conversion until acquisition succeeds again.

The analysis must begin a new segment after each model reset.
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

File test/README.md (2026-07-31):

# Test

Validation scripts, bring-up procedures, and test logs.

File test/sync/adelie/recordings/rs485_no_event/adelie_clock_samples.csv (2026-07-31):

sequence | t1_adelie_ns | t2_korora_ticks | t3_korora_ticks | t4_adelie_ns | network_rtt_ns | full_exchange_us | midpoint_adelie_ns | midpoint_korora_ticks
1 | 29981078580980 | 591268921 | 591542822 | 29981168389759 | 72689966.5 | 89808.779 | 29981123485369.5 | 591405871.5
2 | 29982079811348 | 607107456 | 607381619 | 29982158614152 | 61667616.5 | 78802.804 | 29982119212750.0 | 607244537.5
3 | 29983079846554 | 622958801 | 623231792 | 29983148355047 | 51446555.5 | 68508.493 | 29983114100800.5 | 623095296.5
4 | 29984080179308 | 638787397 | 639055197 | 29984138530855 | 41614047.0 | 58351.547 | 29984109355081.5 | 638921297.0
5 | 29985079226851 | 654627358 | 654900820 | 29985128548083 | 32229857.0 | 49321.232 | 29985103887467.0 | 654764089.0
6 | 29986080274076 | 671187311 | 671457688 | 29986164547836 | 67375197.5 | 84273.76 | 29986122410956.0 | 671322499.5
7 | 29987079915051 | 687027285 | 687302311 | 29987153432915 | 56328739.0 | 73517.864 | 29987116673983.0 | 687164798.0
8 | 29988079819114 | 702867186 | 703141040 | 29988144360894 | 47425905.0 | 64541.78 | 29988112090004.0 | 703004113.0
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

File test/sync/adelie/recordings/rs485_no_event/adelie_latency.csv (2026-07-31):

sequence | model_generation | model_points | model_slope_error_ppm | model_min_network_rtt_us | model_median_network_rtt_us | adelie_t1_ns | adelie_t7_ns | total_rtt_us | ble_down_est_us | ble_up_est_us | korora_rx_ticks | i2c_tx_start_ticks | reward_rx_hub_ticks | reward_exec_hub_ticks | korora_ack_rx_ticks | korora_done_tx_ticks | korora_queue_to_i2c_us | korora_post_ack_us | reward_model_valid | i2c_down_us | reward_action_us | i2c_up_and_poll_us | korora_reward_rtt_us | korora_internal_us
10000 | 1 | 16 | -242.33902750603332 | 32229.857 | 53942.04775 | 29996155768012 | 29996289459968 | 133691.956 | 46716.91062164307 | 57287.20909881592 | 832473996 | 832751340 | 832758204 | 832758272 | 832947613 | 832948483 | 17334.0 | 54.375 | 1 | 429.0 | 4.25 | 11833.8125 | 12267.0625 | 29655.4375
10001 | 1 | 16 | -242.33902750603332 | 32229.857 | 53942.04775 | 29996794514620 | 29996919559994 | 125045.374 | 38853.90835571289 | 56982.974769592285 | 842565657 | 842835738 | 842841528 | 842841596 | 843031639 | 843032508 | 16880.0625 | 54.3125 | 1 | 361.875 | 4.25 | 11877.6875 | 12243.8125 | 29178.1875
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

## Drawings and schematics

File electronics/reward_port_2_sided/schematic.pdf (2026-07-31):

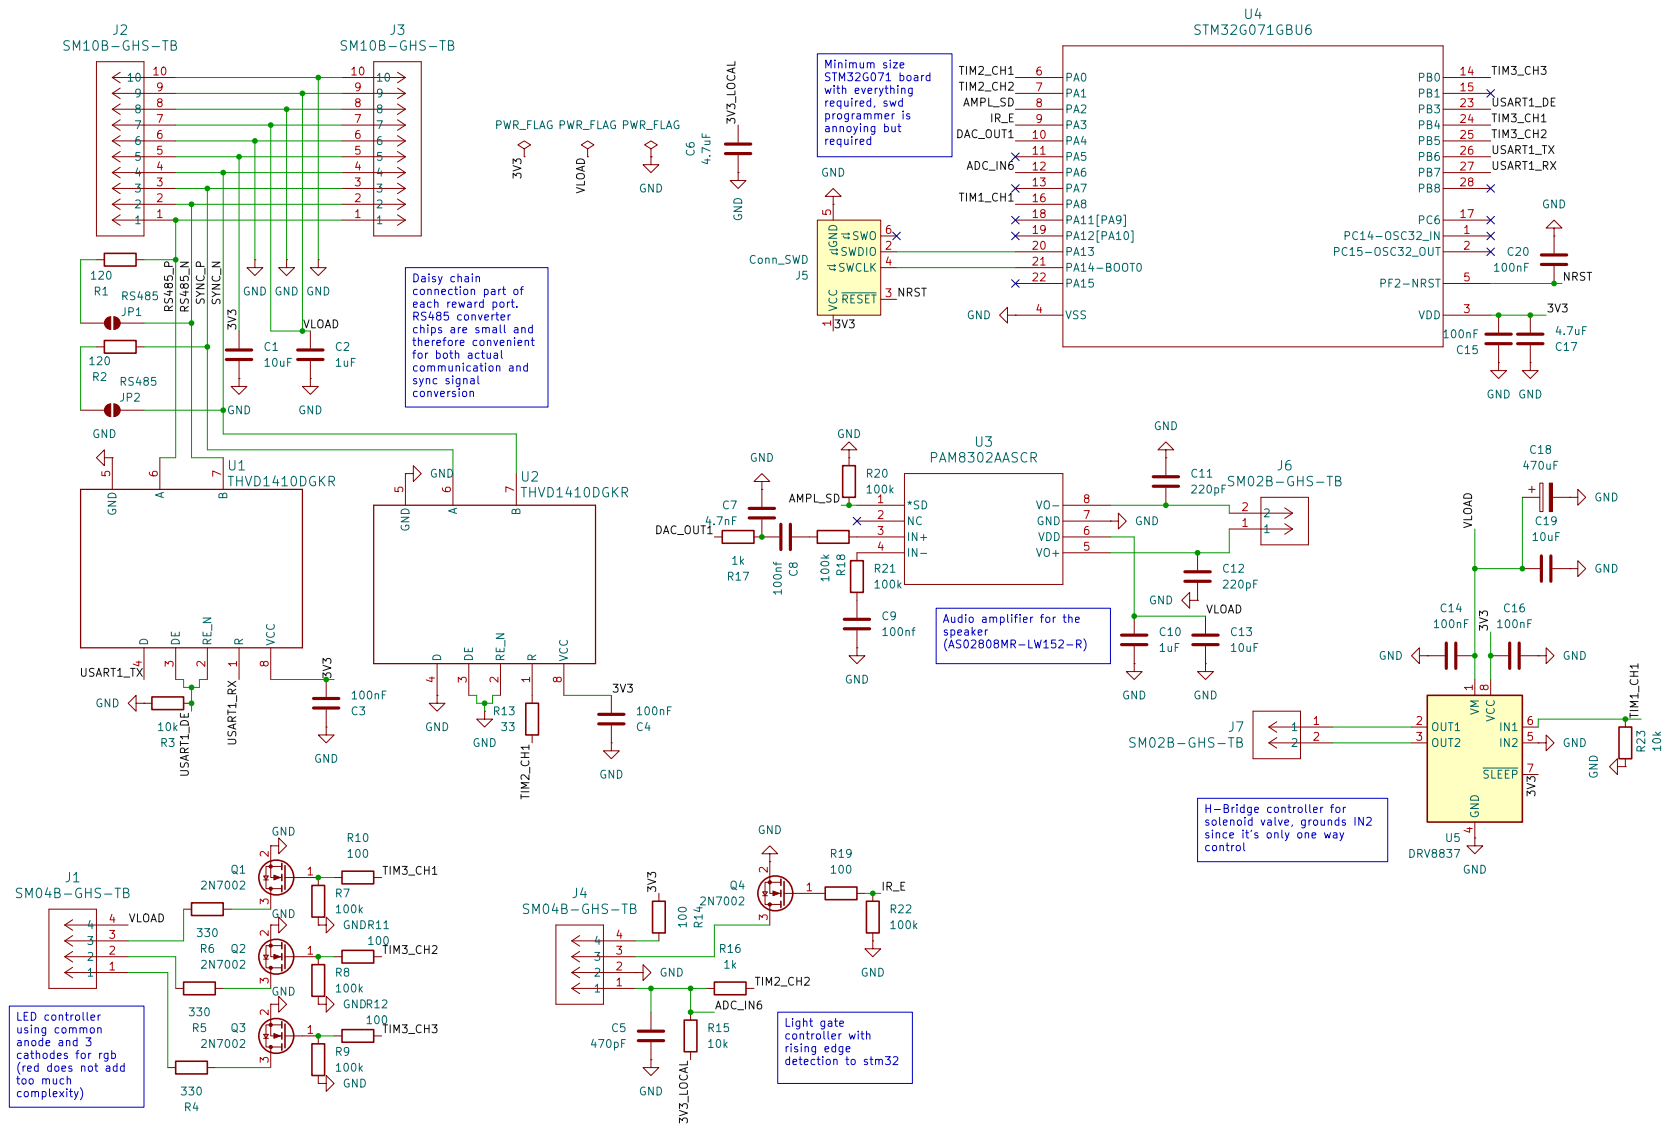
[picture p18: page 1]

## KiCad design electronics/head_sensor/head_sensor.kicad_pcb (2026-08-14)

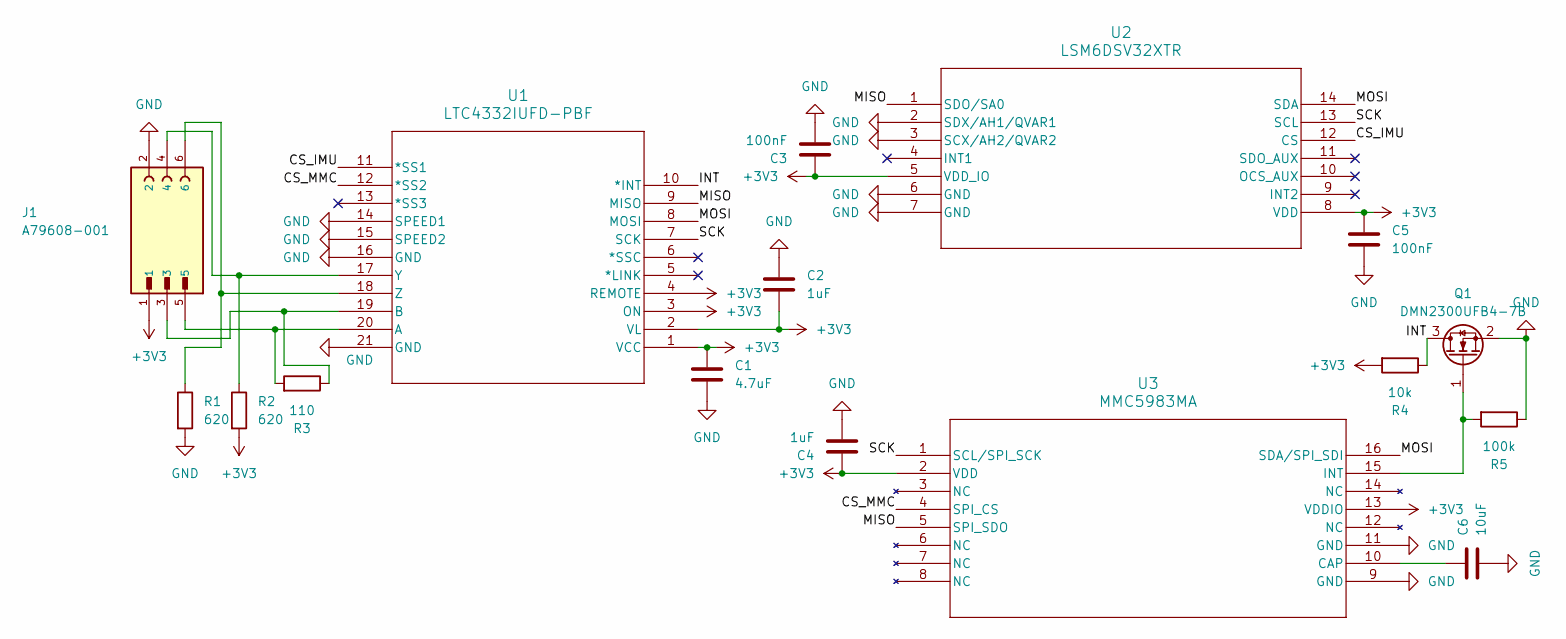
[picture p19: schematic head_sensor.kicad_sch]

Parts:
C1: 4.7uF; C_0603_1608Metric
C2, C4: 1uF; C_0402_1005Metric
C3, C5: 100nF; C_0402_1005Metric
C6: 10uF; C_0603_1608Metric
J1: A79608-001; OMNETICS_A79607-001; PARTREV D
Q1: DMN2300UFB4-7B; Diodes_DFN1006-3
R1, R2: 620; R_0402_1005Metric
R3: 110; R_0402_1005Metric
R4: 10k; R_0402_1005Metric
R5: 100k; R_0402_1005Metric
U1: LTC4332IUFD-PBF; UFD_05-08-1711_ADI
U2: LSM6DSV32XTR; LGA-14_3x2.5mm_P0.5mm_LayoutBorder3x4y
U3: MMC5983MA; LGA-16_3x3mm_P0.5mm

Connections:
+3V3: C1.1, C2.2, C3.1, C4.1, C5.1, J1.1, R2.2, R4.2, U1.1 (VCC), U1.2 (VL), U1.3 (ON), U1.4 (REMOTE), U2.5 (VDD_IO), U2.8 (VDD), U3.2 (VDD), U3.13 (VDDIO)
/CS_IMU: U1.11 (*SS1), U2.12 (CS)
/CS_MMC: U1.12 (*SS2), U3.4 (SPI_CS)
/INT: Q1.3 (D), R4.1, U1.10 (*INT)
/MISO: U1.9 (MISO), U2.1 (SDO/SA0), U3.5 (SPI_SDO)
/MOSI: U1.8 (MOSI), U2.14 (SDA), U3.16 (SDA/SPI_SDI)
/SCK: U1.7 (SCK), U2.13 (SCL), U3.1 (SCL/SPI_SCK)
GND: C1.2, C2.1, C3.2, C4.2, C5.2, C6.2, J1.2, Q1.2 (S), R1.2, R5.1, U1.14 (SPEED1), U1.15 (SPEED2), U1.16 (GND), U1.21 (GND), U2.2 (SDX/AH1/QVAR1), U2.3 (SCX/AH2/QVAR2), U2.6 (GND), U2.7 (GND), U3.9 (GND), U3.11 (GND)
unnamed: Q1.1 (G), R5.2, U3.15 (INT)
unnamed: J1.5, R3.2, U1.20 (A)
unnamed: J1.3, R3.1, U1.19 (B)
unnamed: J1.4, R2.1, U1.17 (Y)
unnamed: J1.6, R1.1, U1.18 (Z)
unnamed: C6.1, U3.10 (CAP)

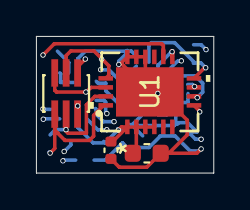
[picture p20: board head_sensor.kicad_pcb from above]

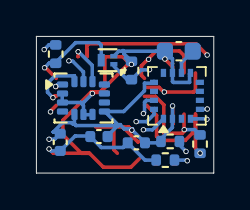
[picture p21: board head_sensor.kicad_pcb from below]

Board: 4 copper layers, 9.8 x 7.6 mm, 16 parts (12 on the bottom side), 14 nets.

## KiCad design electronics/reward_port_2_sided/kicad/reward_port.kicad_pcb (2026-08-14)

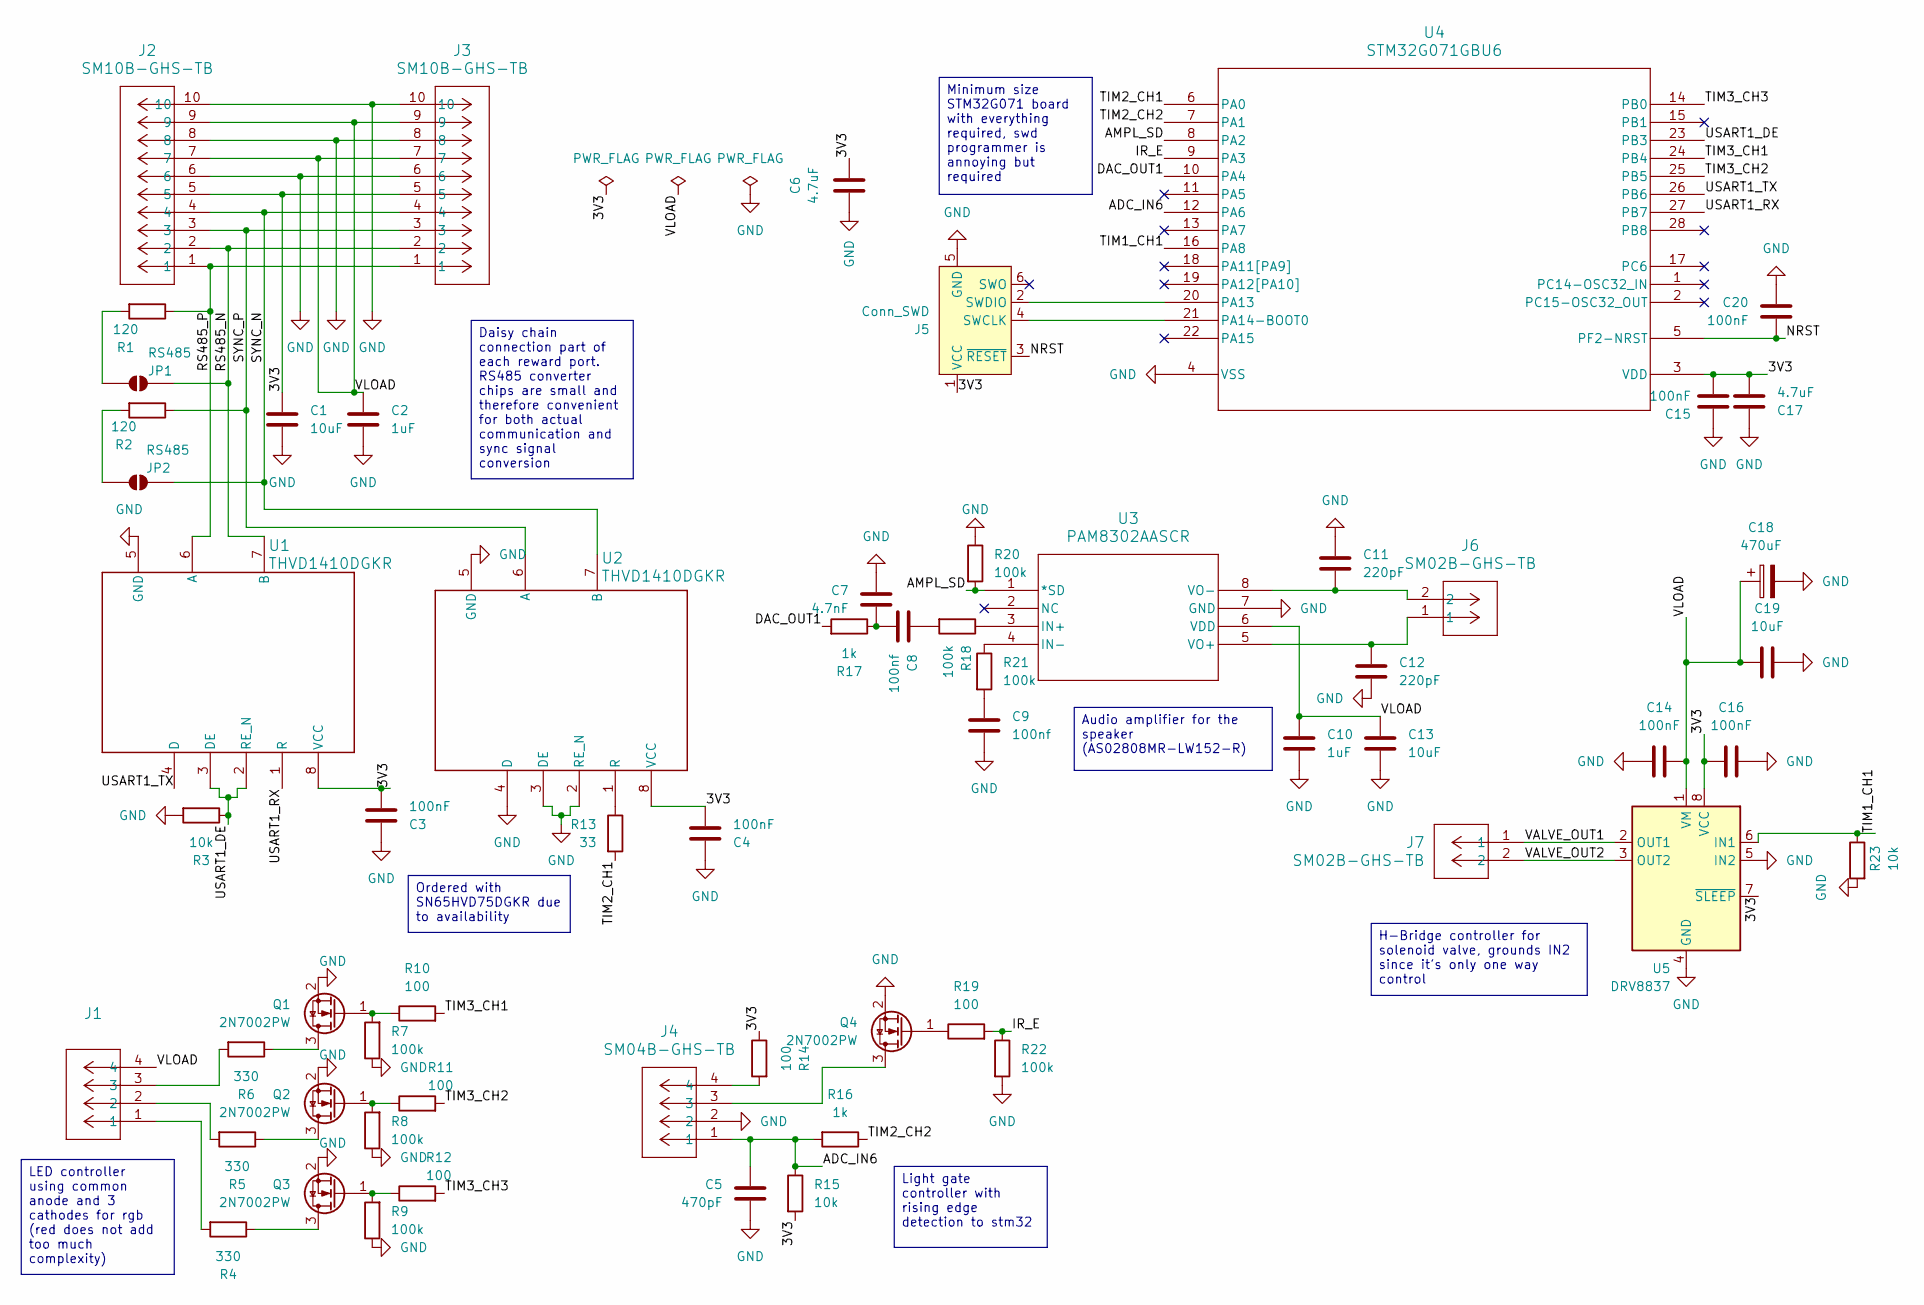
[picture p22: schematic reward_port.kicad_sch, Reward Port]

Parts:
C1, C19: 10uF; C_0603_1608Metric
C2, C10: 1uF; C_0402_1005Metric
C3, C4, C14, C15, C16, C20: 100nF; C_0402_1005Metric
C5: 470pF; C_0402_1005Metric
C6, C17: 4.7uF; C_0603_1608Metric
C7: 4.7nF; C_0402_1005Metric
C8, C9: 100nf; C_0402_1005Metric
C11, C12: 220pF; C_0402_1005Metric
C13: 10uF; C_0805_2012Metric
C18: 470uF; CP_EIA-7343-43_Kemet-X
J1, J4: SM04B-GHS-TB; JST_GH_SM04B-GHS-TB_1x04-1MP_P1.25mm_Horizontal
J2, J3: SM10B-GHS-TB; JST_PH_S10B-PH-SM4-TB_1x10-1MP_P2.00mm_Horizontal
J5: Conn_SWD; Tag-Connect_TC2030-IDC-NL_2x03_P1.27mm_Vertical
J6, J7: SM02B-GHS-TB; JST_GH_SM02B-GHS-TB_1x02-1MP_P1.25mm_Horizontal
JP1, JP2: RS485; SolderJumper-2_P1.3mm_Open_RoundedPad1.0x1.5mm
Q1, Q2, Q3, Q4: 2N7002PW; SOT-323_SC-70
R1, R2: 120; R_0603_1608Metric
R3, R15, R23: 10k; R_0402_1005Metric
R4, R5, R6: 330; R_0402_1005Metric
R7, R8, R9, R18, R20, R21, R22: 100k; R_0402_1005Metric
R10, R11, R12, R19: 100; R_0402_1005Metric
R13: 33; R_0402_1005Metric
R14: 100; R_0603_1608Metric
R16, R17: 1k; R_0402_1005Metric
U1, U2: THVD1410DGKR; VSSOP-8_3x3mm_P0.65mm
U3: PAM8302AASCR; PAM8302AASCR_DIO
U4: STM32G071GBU6; QFN-28_4x4mm_P0.5mm
U5: DRV8837; WSON-8-1EP_2x2mm_P0.5mm_EP0.9x1.6mm

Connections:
/3V3: C1.1, C3.1, C4.1, C6.1, C15.2, C16.1, C17.1, J2.5, J3.5, J5.1 (VCC), R14.1, R15.2, U1.8 (VCC), U2.8 (VCC), U4.3 (VDD), U5.7 (~SLEEP), U5.8 (VCC)
/ADC_IN6: C5.2, J4.1, R15.1, R16.2, U4.12 (PA6)
/AMPL_SD: R20.2, U3.1 (*SD), U4.8 (PA2)
/DAC_OUT1: R17.2, U4.10 (PA4)
/IR_E: R19.2, R22.1, U4.9 (PA3)
/NRST: C20.1, J5.3 (~RESET), U4.5 (PF2-NRST)
/RS485_N: J2.2, J3.2, JP1.2 (B), U1.7 (B)
/RS485_P: J2.1, J3.1, R1.1, U1.6 (A)
/SYNC_N: J2.4, J3.4, JP2.2 (B), U2.7 (B)
/SYNC_P: J2.3, J3.3, R2.1, U2.6 (A)
/TIM1_CH1: R23.1, U4.16 (PA8), U5.6 (IN1)
/TIM2_CH1: R13.2, U4.6 (PA0)
/TIM2_CH2: R16.1, U4.7 (PA1)
/TIM3_CH1: R10.2, U4.24 (PB4)
/TIM3_CH2: R11.2, U4.25 (PB5)
/TIM3_CH3: R12.2, U4.14 (PB0)
/USART1_DE: R3.1, U1.2 (RE_N), U1.3 (DE), U4.23 (PB3)
/USART1_RX: U1.1 (R), U4.27 (PB7)
/USART1_TX: U1.4 (D), U4.26 (PB6)
/VALVE_OUT1: J7.1, U5.2 (OUT1)
/VALVE_OUT2: J7.2, U5.3 (OUT2)
/VLOAD: C2.1, C10.1, C13.1, C14.1, C18.1, C19.1, J1.4, J2.7, J2.9, J3.7, J3.9, U3.6 (VDD), U5.1 (VM)
GND: C1.2, C2.2, C3.2, C4.2, C5.1, C6.2, C7.1, C9.2, C10.2, C11.1, C12.1, C13.2, C14.2, C15.1, C16.2, C17.2, C18.2, C19.2, C20.2, J2.6, J2.8, J2.10, J3.6, J3.8, J3.10, J4.2, J5.5 (GND), Q1.2 (S), Q2.2 (S), Q3.2 (S), Q4.2 (S), R3.2, R7.1, R8.1, R9.1, R20.1, R22.2, R23.2, U1.5 (GND), U2.2 (RE_N), U2.3 (DE), U2.4 (D), U2.5 (GND), U3.7 (GND), U4.4 (VSS), U5.4 (GND), U5.5 (IN2), U5.9 (GND)
unnamed: C7.2, C8.2, R17.1
unnamed: C8.1, R18.2
unnamed: C9.1, R21.2
unnamed: J1.1, R4.2
unnamed: J1.2, R5.2
unnamed: J1.3, R6.2
unnamed: J4.4, R14.2
unnamed: J5.4 (SWCLK), U4.21 (PA14-BOOT0)
unnamed: J5.2 (SWDIO), U4.20 (PA13)
unnamed: JP1.1 (A), R1.2
unnamed: JP2.1 (A), R2.2
unnamed: Q1.3 (D), R6.1
unnamed: Q1.1 (G), R7.2, R10.1
unnamed: Q2.3 (D), R5.1
unnamed: Q2.1 (G), R8.2, R11.1
unnamed: Q3.3 (D), R4.1
unnamed: Q3.1 (G), R9.2, R12.1
unnamed: J4.3, Q4.3 (D)
unnamed: Q4.1 (G), R19.1
unnamed: R13.1, U2.1 (R)
unnamed: R18.1, U3.3 (IN+)
unnamed: R21.1, U3.4 (IN-)
unnamed: C12.2, J6.1, U3.5 (VO+)
unnamed: C11.2, J6.2, U3.8 (VO-)

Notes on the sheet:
Audio amplifier for the speaker (AS02808MR-LW152-R)
Light gate controller with rising edge detection to stm32
H-Bridge controller for solenoid valve, grounds IN2 since it's only one way control
Daisy chain connection part of each reward port. RS485 converter chips are small and therefore convenient for both actual communication and sync signal conversion
Minimum size STM32G071 board with everything required, swd programmer is annoying but required
Ordered with SN65HVD75DGKR due to availability
LED controller using common anode and 3 cathodes for rgb (red does not add too much complexity)

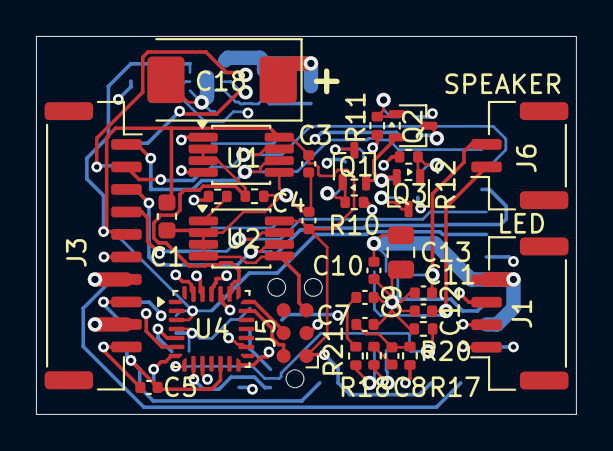
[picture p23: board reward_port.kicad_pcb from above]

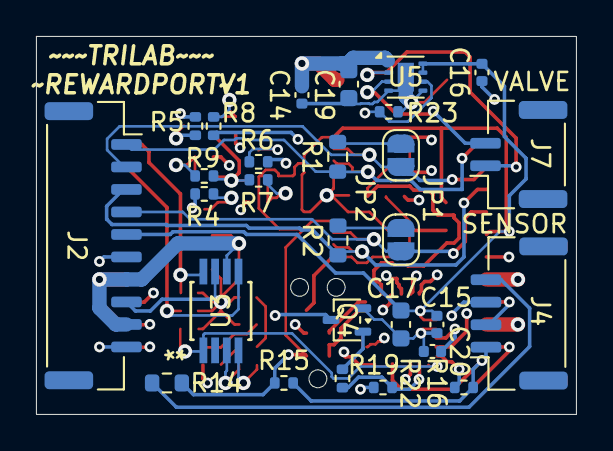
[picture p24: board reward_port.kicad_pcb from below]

Board: 4 copper layers, 30.0 x 21.0 mm, 59 parts (28 on the bottom side), 47 nets.

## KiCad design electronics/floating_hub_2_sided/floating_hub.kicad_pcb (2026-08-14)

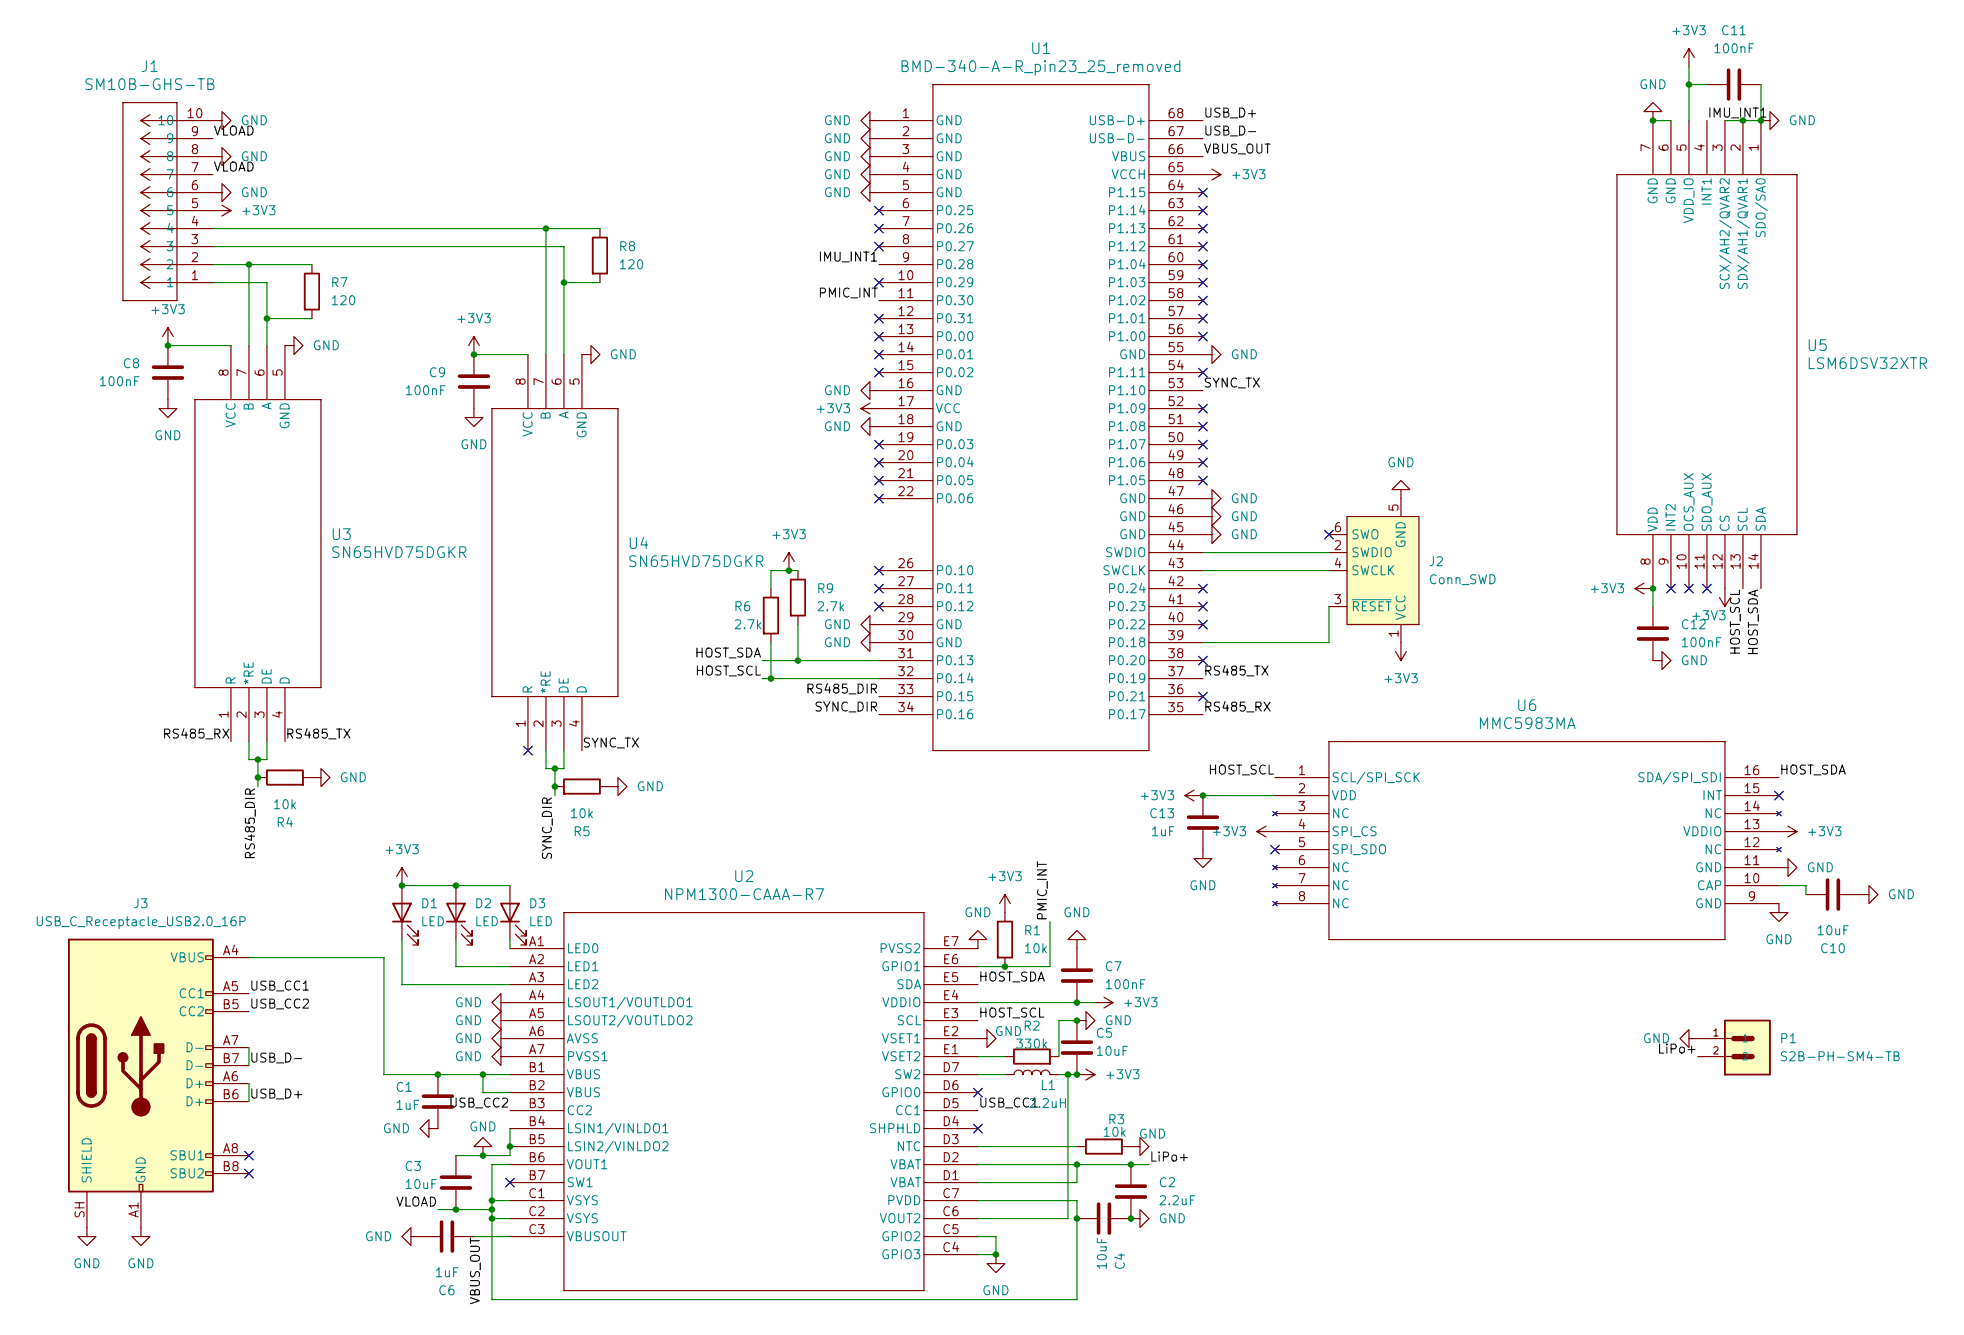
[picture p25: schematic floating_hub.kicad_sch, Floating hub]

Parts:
C1, C6, C13: 1uF; C_0603_1608Metric
C2: 2.2uF; C_0603_1608Metric
C3, C4, C5, C10: 10uF; C_0603_1608Metric
C7, C8, C9, C11, C12: 100nF; C_0402_1005Metric
D1, D2, D3: LED; LED_0402_1005Metric
J1: SM10B-GHS-TB; JST_GH_SM10B-GHS-TB_1x10-1MP_P1.25mm_Horizontal
J2: Conn_SWD; Tag-Connect_TC2030-IDC-NL_2x03_P1.27mm_Vertical
J3: USB_C_Receptacle_USB2.0_16P; USB_C_Receptacle_GCT_USB4110
L1: 2.2uH; L_0805_2012Metric
P1: S2B-PH-SM4-TB; JST_PH_S2B-PH-SM4-TB_1x02-1MP_P2.00mm_Horizontal
R1, R3, R4, R5: 10k; R_0402_1005Metric
R2: 330k; R_0402_1005Metric
R6, R9: 2.7k; R_0402_1005Metric
R7, R8: 120; R_0402_1005Metric
U1: BMD-340-A-R_pin23_25_removed; BMD-340_UBL_ncs_removed
U2: NPM1300-CAAA-R7; WLCSP35_2p3775X3p0775_NOR
U3, U4: SN65HVD75DGKR; DGK8_TEX
U5: LSM6DSV32XTR; LGA-14_3x2.5mm_P0.5mm_LayoutBorder3x4y
U6: MMC5983MA; LGA-16_3x3mm_P0.5mm

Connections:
+3V3: C5.2, C7.2, C8.2, C9.2, C11.1, C12.1, C13.2, D1.2 (A), D2.2 (A), D3.2 (A), J1.5, J2.1 (VCC), L1.2, R1.1, R6.1, R9.1, U1.17 (VCC), U1.65 (VCCH), U2.C6 (VOUT2), U2.E4 (VDDIO), U3.8 (VCC), U4.8 (VCC), U5.5 (VDD_IO), U5.8 (VDD), U5.12 (CS), U6.2 (VDD), U6.4 (SPI_CS), U6.13 (VDDIO)
/HOST_SCL: R6.2, U1.32 (P0.14), U2.E3 (SCL), U5.13 (SCL), U6.1 (SCL/SPI_SCK)
/HOST_SDA: R9.2, U1.31 (P0.13), U2.E5 (SDA), U5.14 (SDA), U6.16 (SDA/SPI_SDI)
/IMU_INT1: U1.9 (P0.28), U5.4 (INT1)
/LiPo+: C2.1, P1.2, U2.D1 (VBAT), U2.D2 (VBAT)
/PMIC_INT: R1.2, U1.11 (P0.30), U2.E6 (GPIO1)
/RS485_DIR: R4.1, U1.33 (P0.15), U3.2 (*RE), U3.3 (DE)
/RS485_RX: U1.35 (P0.17), U3.1 (R)
/RS485_TX: U1.37 (P0.19), U3.4 (D)
/SYNC_DIR: R5.2, U1.34 (P0.16), U4.2 (*RE), U4.3 (DE)
/SYNC_TX: U1.53 (P1.10), U4.4 (D)
/USB_CC1: J3.A5 (CC1), U2.D5 (CC1)
/USB_CC2: J3.B5 (CC2), U2.B3 (CC2)
/USB_D+: J3.A6 (D+), J3.B6 (D+), U1.68 (USB-D+)
/USB_D-: J3.A7 (D-), J3.B7 (D-), U1.67 (USB-D-)
/VBUS_OUT: C6.1, U1.66 (VBUS), U2.C3 (VBUSOUT)
/VLOAD: C3.2, C4.2, J1.7, J1.9, U2.B6 (VOUT1), U2.C1 (VSYS), U2.C2 (VSYS), U2.C7 (PVDD)
GND: C1.2, C2.2, C3.1, C4.1, C5.1, C6.2, C7.1, C8.1, C9.1, C10.2, C11.2, C12.2, C13.1, J1.6, J1.8, J1.10, J2.5 (GND), J3.A1 (GND), J3.A12 (GND), J3.B1 (GND), J3.B12 (GND), J3.SH (SHIELD), P1.1, R2.2, R3.2, R4.2, R5.1, U1.1 (GND), U1.2 (GND), U1.3 (GND), U1.4 (GND), U1.5 (GND), U1.16 (GND), U1.18 (GND), U1.29 (GND), U1.30 (GND), U1.45 (GND), U1.46 (GND), U1.47 (GND), U1.55 (GND), U2.A4 (LSOUT1/VOUTLDO1), U2.A5 (LSOUT2/VOUTLDO2), U2.A6 (AVSS), U2.A7 (PVSS1), U2.B4 (LSIN1/VINLDO1), U2.B5 (LSIN2/VINLDO2), U2.C4 (GPIO3), U2.C5 (GPIO2), U2.E2 (VSET1), U2.E7 (PVSS2), U3.5 (GND), U4.5 (GND), U5.1 (SDO/SA0), U5.2 (SDX/AH1/QVAR1), U5.3 (SCX/AH2/QVAR2), U5.6 (GND), U5.7 (GND), U6.9 (GND), U6.11 (GND)
unnamed: C1.1, J3.A4 (VBUS), J3.A9 (VBUS), J3.B4 (VBUS), J3.B9 (VBUS), U2.B1 (VBUS), U2.B2 (VBUS)
unnamed: D1.1 (K), U2.A3 (LED2)
unnamed: D2.1 (K), U2.A2 (LED1)
unnamed: D3.1 (K), U2.A1 (LED0)
unnamed: J2.4 (SWCLK), U1.43 (SWCLK)
unnamed: J2.2 (SWDIO), U1.44 (SWDIO)
unnamed: J2.3 (~RESET), U1.39 (P0.18)
unnamed: R3.1, U2.D3 (NTC)
unnamed: L1.1, U2.D7 (SW2)
unnamed: R2.1, U2.E1 (VSET2)
unnamed: J1.1, R7.2, U3.6 (A)
unnamed: J1.2, R7.1, U3.7 (B)
unnamed: J1.3, R8.2, U4.6 (A)
unnamed: J1.4, R8.1, U4.7 (B)
unnamed: C10.1, U6.10 (CAP)

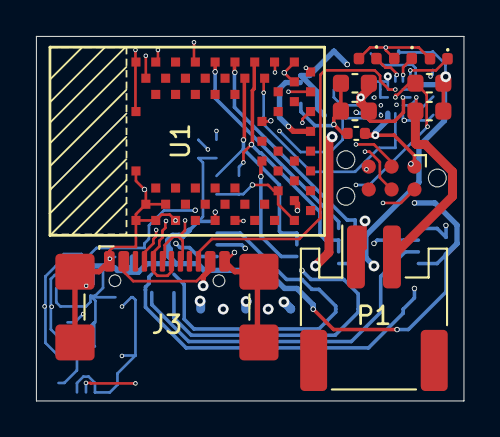
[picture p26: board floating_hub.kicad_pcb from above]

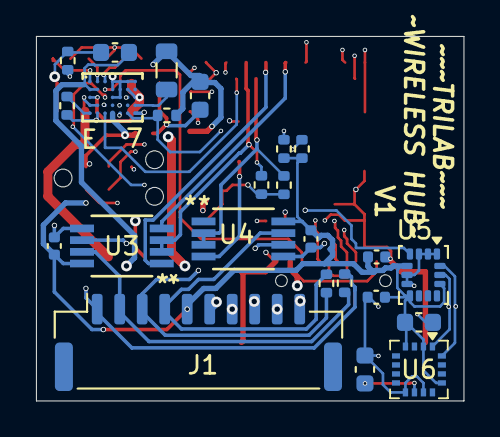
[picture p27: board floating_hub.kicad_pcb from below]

Board: 4 copper layers, 23.8 x 20.2 mm, 36 parts (24 on the bottom side), 33 nets.

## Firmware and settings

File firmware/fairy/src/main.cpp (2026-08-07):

#include <cstdint>

#include <stm32g0xx_hal.h>

#include "application.hpp"
#include "board_profile.hpp"
#include "debug_log.hpp"
#include "fairy_shared/adelie_protocol.hpp"
#include "fairy_shared/fairy_protocol.hpp"
#include "fairy_shared/tlv.hpp"
#include "light_sensor.hpp"
#include "outputs.hpp"
#include "record_store.hpp"
#include "rs485_link.hpp"
#include "timebase.hpp"

namespace {

IWDG_HandleTypeDef watchdog;
const char *current_boot_stage = "reset";
bool debug_ready;

void report_boot_stage(const char *stage) {
  current_boot_stage = stage;
  if (debug_ready) {
    fairy_debug::log("BOOT_STAGE %s\r\n", stage);
    fairy_debug::service();
  }
}

void system_clock_initialize() {
  RCC_OscInitTypeDef oscillator{};
  oscillator.OscillatorType = RCC_OSCILLATORTYPE_HSI;
  oscillator.HSIState = RCC_HSI_ON;
  oscillator.HSIDiv = RCC_HSI_DIV1;
  oscillator.HSICalibrationValue = RCC_HSICALIBRATION_DEFAULT;
  oscillator.PLL.PLLState = RCC_PLL_ON;
  oscillator.PLL.PLLSource = RCC_PLLSOURCE_HSI;
  oscillator.PLL.PLLM = RCC_PLLM_DIV1;
  oscillator.PLL.PLLN = 8;
  oscillator.PLL.PLLP = RCC_PLLP_DIV2;
  oscillator.PLL.PLLQ = RCC_PLLQ_DIV2;
  oscillator.PLL.PLLR = RCC_PLLR_DIV2;
  if (HAL_RCC_OscConfig(&oscillator) != HAL_OK) {
    Error_Handler();
  }

  RCC_ClkInitTypeDef clock{};
  clock.ClockType =
      RCC_CLOCKTYPE_HCLK | RCC_CLOCKTYPE_SYSCLK | RCC_CLOCKTYPE_PCLK1;
  clock.SYSCLKSource = RCC_SYSCLKSOURCE_PLLCLK;
  clock.AHBCLKDivider = RCC_SYSCLK_DIV1;
  clock.APB1CLKDivider = RCC_HCLK_DIV1;
  if (HAL_RCC_ClockConfig(&clock, FLASH_LATENCY_2) != HAL_OK) {
    Error_Handler();
  }
}

void watchdog_initialize() {
  __HAL_RCC_LSI_ENABLE();
  while (__HAL_RCC_GET_FLAG(RCC_FLAG_LSIRDY) == RESET) {
  }
  watchdog.Instance = IWDG;
  watchdog.Init.Prescaler = IWDG_PRESCALER_32;
  watchdog.Init.Window = IWDG_WINDOW_DISABLE;
  watchdog.Init.Reload = 1000;
  if (HAL_IWDG_Init(&watchdog) != HAL_OK) {
    Error_Handler();
  }
}

} // namespace

int main() {
  const std::uint32_t reset_cause = RCC->CSR;
  HAL_Init();
  system_clock_initialize();
  __HAL_RCC_CLEAR_RESET_FLAGS();

  fairy_board::initialize_safe_gpio();
  fairy_debug::initialize();
  debug_ready = true;

  fairy_debug::log(
      "FAIRY_BUILD profile=%s timer_hz=16000000 rs485_baud=460800\r\n",
      fairy_board::name);
  fairy_debug::service();

  report_boot_stage("record_store");
  fairy_records::initialize();

  report_boot_stage("alternate_functions");
  fairy_board::initialize_alternate_functions();

  report_boot_stage("timebase");
  fairy_timebase::initialize();

  /*
   * Communications are initialized before optional measurement and output
   * peripherals. Incoming bytes are buffered by the USART interrupt while
   * the remaining short self tests complete.
   */
  report_boot_stage("rs485");
  fairy_rs485::initialize();

  report_boot_stage("outputs");
  fairy_outputs::initialize();

  report_boot_stage("light_sensor");
  const bool light_initialized = fairy_light::initialize();
  const fairy_light::SelfTest light_test =
      light_initialized
          ? fairy_light::self_test()
          : fairy_light::SelfTest{0xFFFFU, 0xFFFFU, false, 0, 0, true};

  report_boot_stage("application");
  fairy_application::initialize(reset_cause, light_test.passed, light_test.dark,
                                light_test.clear);

  report_boot_stage("watchdog");
  watchdog_initialize();

  report_boot_stage("ready");
  fairy_debug::log(
      "FAIRY_READY light_initialized=%u light_passed=%u dark=%u clear=%u "
      "gate_clear=%u gate_blocked=%u gate_fixed=%u\r\n",
      light_initialized ? 1U : 0U, light_test.passed ? 1U : 0U,
      static_cast<unsigned int>(light_test.dark),
      static_cast<unsigned int>(light_test.clear),
      static_cast<unsigned int>(light_test.clear_threshold),
      static_cast<unsigned int>(light_test.blocked_threshold),
      light_test.fixed_thresholds ? 1U : 0U);
  fairy_debug::service();

  while (true) {
    fairy_rs485::service();
    fairy_application::service();
    fairy_debug::service();
    (void)HAL_IWDG_Refresh(&watchdog);
    __WFI();
  }
}

extern "C" void SysTick_Handler() { HAL_IncTick(); }

extern "C" void Error_Handler() {
  if (debug_ready) {
    fairy_debug::log("FATAL stage=%s\r\n", current_boot_stage);
    fairy_debug::service();
  }
  __disable_irq();
  fairy_board::initialize_safe_gpio();
  while (true) {
  }
}

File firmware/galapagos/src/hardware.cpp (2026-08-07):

#include "hardware.hpp"

#include <cerrno>

#include <gpiote_nrfx.h>
#include <hal/nrf_gpio.h>
#include <helpers/nrfx_gppi.h>
#include <nrfx_gpiote.h>
#include <nrfx_grtc.h>

#include <zephyr/devicetree.h>
#include <zephyr/irq.h>
#include <zephyr/kernel.h>
#include <zephyr/sys/atomic.h>
#include <zephyr/sys/util.h>

#include "debug_log.hpp"
#include "fairy_shared/fairy_protocol.hpp"
#include "fairy_shared/static_queue.hpp"
#include "fairy_shared/tlv.hpp"
#include "record_stream.hpp"

namespace galapagos_hardware {
namespace {

#define USER_NODE DT_PATH(zephyr_user)
#define EVENT_INPUT_PIN NRF_DT_GPIOS_TO_PSEL(USER_NODE, event_gpios)
#define EVENT_GPIOTE_NODE NRF_DT_GPIOTE_NODE(USER_NODE, event_gpios)
#define TTL_OUTPUT_PIN NRF_DT_GPIOS_TO_PSEL(USER_NODE, ttl_output_gpios)
#define TTL_GPIOTE_NODE NRF_DT_GPIOTE_NODE(USER_NODE, ttl_output_gpios)

BUILD_ASSERT(DT_SAME_NODE(EVENT_GPIOTE_NODE, TTL_GPIOTE_NODE),
             "event and TTL pins must use the same GPIOTE instance");

nrfx_gpiote_t *const gpiote = &GPIOTE_NRFX_INST_BY_NODE(EVENT_GPIOTE_NODE);
std::uint8_t event_gpiote_channel;
std::uint8_t event_grtc_channel;
nrfx_gppi_handle_t event_connection;
std::uint8_t ttl_gpiote_channel;
std::uint8_t ttl_set_channel;
std::uint8_t ttl_clear_channel;
nrfx_gppi_handle_t ttl_set_connection;
nrfx_gppi_handle_t ttl_clear_connection;
atomic_t pulse_armed;
atomic_t active_session;
atomic_t event_sequence;

struct Pulse {
  std::uint32_t sequence{};
  std::uint64_t target_us{};
  std::uint32_t width_us{};
};

Pulse pulse;
fairy::StaticQueue<Pulse, 8> pending_pulses;
k_spinlock pulse_lock;
std::uint64_t last_queued_target_us;

void program_pulse(const Pulse &next) {
  pulse = next;
  nrfx_gppi_conn_enable(ttl_set_connection);
  nrfx_gppi_conn_enable(ttl_clear_connection);
  /*
   * The optimized GRTC setters require interrupts to be locked. Enabling the
   * channels and using safe setting also prevents a prior compare state from
   * being interpreted as the newly queued pulse.
   */
  const unsigned int key = irq_lock();
  (void)nrfx_grtc_syscounter_cc_int_enable(ttl_set_channel);
  (void)nrfx_grtc_syscounter_cc_int_enable(ttl_clear_channel);
  nrfx_grtc_syscounter_cc_abs_set(ttl_set_channel, pulse.target_us, true);
  nrfx_grtc_syscounter_cc_abs_set(ttl_clear_channel,
                                  pulse.target_us + pulse.width_us, true);
  irq_unlock(key);
}

int wait_for_grtc() {
  nrfx_grtc_active_request_set(true);
  for (std::uint32_t attempt = 0; attempt < 10'000; ++attempt) {
    if (nrfx_grtc_ready_check()) {
      return 0;
    }
    k_busy_wait(10);
  }
  return -ETIMEDOUT;
}

void gpiote_irq_wrapper(const void *argument) {
  nrfx_gpiote_irq_handler(
      static_cast<nrfx_gpiote_t *>(const_cast<void *>(argument)));
}

void event_handler(nrfx_gpiote_pin_t, nrfx_gpiote_trigger_t, void *) {
  std::uint64_t captured_us{};
  if (nrfx_grtc_syscounter_cc_value_read(event_grtc_channel, &captured_us) !=
      0) {
    return;
  }
  const std::uint32_t sequence =
      static_cast<std::uint32_t>(atomic_inc(&event_sequence) + 1);
  std::uint8_t payload[24]{};
  fairy::protocol::TlvWriter fields(payload, sizeof(payload));
  (void)fields.u32(static_cast<std::uint16_t>(fairy::protocol::Field::sequence),
                   sequence);
  (void)fields.u8(static_cast<std::uint16_t>(fairy::protocol::Field::state), 1);
  (void)galapagos_stream::publish_record(
      fairy::protocol::RecordType::digital_input,
      fairy::protocol::critical | fairy::protocol::actual_time,
      captured_us * 16ULL,
      static_cast<std::uint32_t>(atomic_get(&active_session)), payload,
      fields.size());
}

void ttl_set_handler(std::int32_t id, std::uint64_t cc_value, void *) {
  if (id != static_cast<std::int32_t>(ttl_set_channel)) {
    return;
  }
  std::uint8_t payload[40]{};
  fairy::protocol::TlvWriter fields(payload, sizeof(payload));
  (void)fields.u32(static_cast<std::uint16_t>(fairy::protocol::Field::sequence),
                   pulse.sequence);
  (void)fields.u64(
      static_cast<std::uint16_t>(fairy::protocol::Field::requested_ticks),
      pulse.target_us * 16ULL);
  (void)fields.u64(
      static_cast<std::uint16_t>(fairy::protocol::Field::actual_ticks),
      cc_value * 16ULL);
  (void)fields.u32(
      static_cast<std::uint16_t>(fairy::protocol::Field::duration_us),
      pulse.width_us);
  (void)galapagos_stream::publish_record(
      fairy::protocol::RecordType::ttl_generated,
      fairy::protocol::critical | fairy::protocol::actual_time |
          fairy::protocol::scheduled,
      cc_value * 16ULL, static_cast<std::uint32_t>(atomic_get(&active_session)),
      payload, fields.size());
}
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

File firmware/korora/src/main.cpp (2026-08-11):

#include <zephyr/kernel.h>

#include "ble_gateway.hpp"
#include "control.hpp"
#include "debug_log.hpp"
#include "experiment.hpp"
#include "fairy_manager.hpp"
#include "galapagos_manager.hpp"
#include "local_sensors.hpp"
#include "rs485_bus.hpp"
#include "timebase.hpp"

namespace {

bool start_component(const char *name, int result) {
  korora_debug::log("START component=%s status=%d\r\n", name, result);
  return result == 0;
}

} // namespace

int main() {
  if (!start_component("timebase", korora_time::initialize()) ||
      !start_component("rs485", korora_rs485::initialize())) {
    return 1;
  }

  korora_galapagos::initialize();
  korora_control::initialize();
  korora_experiment::initialize();

  if (!start_component("fairies", korora_fairies::initialize()) ||
      !start_component("ble", korora_ble::initialize())) {
    return 1;
  }

  // Local sensors deliberately start after BLE so their Fairy telemetry has a
  // transport available immediately. Sensor absence is reported as status and
  // does not make Korora unusable as a communications hub.
  if (!start_component("local_sensors", korora_local_sensors::initialize())) {
    return 1;
  }

  korora_debug::log(
      "READY transport=1 fairy=3 adelie=2 magellan=1 timer_hz=16000000 "
      "sync_hz=4\r\n");
  while (true) {
    k_sleep(K_SECONDS(60));
  }
  return 0;
}

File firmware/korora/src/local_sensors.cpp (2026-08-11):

#include "local_sensors.hpp"

#include <array>
#include <cstddef>
#include <cstdint>
#include <cstring>

#include <zephyr/device.h>
#include <zephyr/devicetree.h>
#include <zephyr/drivers/i2c.h>
#include <zephyr/kernel.h>
#include <zephyr/sys/atomic.h>

#include "ble_gateway.hpp"
#include "debug_log.hpp"
#include "fairy_shared/bytes.hpp"
#include "fairy_shared/fairy_protocol.hpp"
#include "fairy_shared/system_config.hpp"
#include "fairy_shared/tlv.hpp"
#include "timebase.hpp"

namespace korora_local_sensors {
namespace {

// LSM6DSV32X, SDO/SA0 tied low on the prototype.
inline constexpr std::uint16_t imu_address = 0x6AU;
inline constexpr std::uint8_t imu_who_am_i = 0x0FU;
inline constexpr std::uint8_t imu_who_am_i_value = 0x70U;
inline constexpr std::uint8_t imu_ctrl1 = 0x10U;
inline constexpr std::uint8_t imu_ctrl2 = 0x11U;
inline constexpr std::uint8_t imu_ctrl3 = 0x12U;
inline constexpr std::uint8_t imu_ctrl6 = 0x15U;
inline constexpr std::uint8_t imu_outx_l_g = 0x22U;

// MMC5983MA fixed I2C address.
inline constexpr std::uint16_t mag_address = 0x30U;
inline constexpr std::uint8_t mag_status = 0x08U;
inline constexpr std::uint8_t mag_control0 = 0x09U;
inline constexpr std::uint8_t mag_control1 = 0x0AU;
inline constexpr std::uint8_t mag_control2 = 0x0BU;
inline constexpr std::uint8_t mag_product_id = 0x2FU;
inline constexpr std::uint8_t mag_product_id_value = 0x30U;
inline constexpr std::uint8_t mag_xout0 = 0x00U;

inline constexpr std::uint16_t sample_rate_hz = 120U;
inline constexpr std::uint32_t sample_period_us = 1'000'000U / sample_rate_hz;
inline constexpr std::uint32_t live_period_ms = 100U;
inline constexpr std::uint32_t power_period_ms = 1000U;

// Packed IMU dump format v1:
//   uint32 delta_ticks
//   int16  accel_raw[3]
//   int16  gyro_raw[3]
//   int32  mag_raw_centered[3]
// = 28 bytes per sample. Seven samples plus TLV metadata fit under the
// existing 256-byte Fairy record payload maximum.
inline constexpr std::uint8_t sample_format_v1 = 1U;
inline constexpr std::size_t packed_sample_size = 28U;
inline constexpr std::size_t samples_per_chunk = 7U;

const device *const i2c_bus = DEVICE_DT_GET(DT_NODELABEL(i2c1));

atomic_t session_id;
atomic_t telemetry_level = ATOMIC_INIT(1);
atomic_t record_id;
atomic_t chunk_sequence;
atomic_t flush_requested;

k_mutex state_mutex;
Snapshot current_state;

K_THREAD_STACK_DEFINE(sensor_stack, 4096);
k_thread sensor_thread_data;
k_tid_t sensor_thread_id;

struct RawSample {
  std::uint64_t ticks{};
  std::int16_t accel[3]{};
  std::int16_t gyro[3]{};
  std::int32_t mag[3]{};
};

std::array<RawSample, samples_per_chunk> chunk{};
std::size_t chunk_count{};
std::uint32_t chunk_session{};

std::int16_t get_i16(const std::uint8_t *data) {
  return static_cast<std::int16_t>(fairy::wire::get_u16(data));
}

void put_i16(std::uint8_t *destination, std::int16_t value) {
  fairy::wire::put_u16(destination, static_cast<std::uint16_t>(value));
}

void put_i32(std::uint8_t *destination, std::int32_t value) {
  fairy::wire::put_u32(destination, static_cast<std::uint32_t>(value));
}

std::uint32_t next_record_id() {
  return static_cast<std::uint32_t>(atomic_inc(&record_id)) + 1U;
}

std::uint8_t status_bits() {
  k_mutex_lock(&state_mutex, K_FOREVER);
  const std::uint8_t value = current_state.status;
  k_mutex_unlock(&state_mutex);
  return value;
}

void set_status_bit(std::uint8_t mask, bool enabled) {
  k_mutex_lock(&state_mutex, K_FOREVER);
  if (enabled) {
    current_state.status |= mask;
  } else {
    current_state.status &= static_cast<std::uint8_t>(~mask);
  }
  k_mutex_unlock(&state_mutex);
}

void note_i2c_error() {
  k_mutex_lock(&state_mutex, K_FOREVER);
  ++current_state.i2c_errors;
  k_mutex_unlock(&state_mutex);
}

bool publish_record(fairy::protocol::RecordType type, std::uint32_t session,
                    std::uint64_t timestamp_ticks, const std::uint8_t *payload,
                    std::size_t payload_length,
                    bool diagnostic_priority = false) {
  fairy::protocol::RecordHeader header;
  header.type = type;
  header.record_id = next_record_id();
  header.session_id = session;
  header.timestamp_ticks = timestamp_ticks;
  header.clock_hz = fairy::config::common_timer_hz;

  std::uint8_t record[fairy::protocol::fairy_max_record_size]{};
  const std::size_t length = fairy::protocol::encode_record(
      header, payload, payload_length, record, sizeof(record));
  if (length == 0U) {
    return false;
  }

  return korora_ble::send_to_adelie(fairy::config::korora_address,
                                    fairy::transport::Channel::fairy, record,
                                    length, 0U, 0U, 0U, diagnostic_priority);
}

bool probe_imu() {
  std::uint8_t who{};
  if (i2c_reg_read_byte(i2c_bus, imu_address, imu_who_am_i, &who) != 0 ||
      who != imu_who_am_i_value) {
    note_i2c_error();
    return false;
  }

  // CTRL3 defaults to BDU=1 and IF_INC=1. Reassert the documented value so
  // multi-byte reads remain coherent after any previous prototype firmware.
  if (i2c_reg_write_byte(i2c_bus, imu_address, imu_ctrl3, 0x44U) != 0 ||
      // ±500 dps; default LPF selection.
      i2c_reg_write_byte(i2c_bus, imu_address, imu_ctrl6, 0x02U) != 0 ||
      // High-performance 120 Hz accelerometer and gyro.
      i2c_reg_write_byte(i2c_bus, imu_address, imu_ctrl1, 0x06U) != 0 ||
      i2c_reg_write_byte(i2c_bus, imu_address, imu_ctrl2, 0x06U) != 0) {
    note_i2c_error();
    return false;
  }

  return true;
}

bool probe_magnetometer() {
  std::uint8_t product{};
  if (i2c_reg_read_byte(i2c_bus, mag_address, mag_product_id, &product) != 0 ||
      product != mag_product_id_value) {
    note_i2c_error();
    return false;
  }

  // BW=00 gives the 18-bit, 8 ms measurement path. Auto set/reset is useful
  // for a prototype around changing magnetic environments. Continuous mode at
  // 100 Hz is Cmm_en=1, CM_Freq=101.
  if (i2c_reg_write_byte(i2c_bus, mag_address, mag_control0, 0x20U) != 0 ||
      i2c_reg_write_byte(i2c_bus, mag_address, mag_control1, 0x00U) != 0 ||
      i2c_reg_write_byte(i2c_bus, mag_address, mag_control2, 0x0DU) != 0) {
    note_i2c_error();
    return false;
  }

  return true;
}

bool read_imu(RawSample &sample) {
  std::uint8_t raw[12]{};
  if (i2c_burst_read(i2c_bus, imu_address, imu_outx_l_g, raw, sizeof(raw)) !=
      0) {
    note_i2c_error();
    return false;
  }

  sample.gyro[0] = get_i16(raw + 0);
  sample.gyro[1] = get_i16(raw + 2);
  sample.gyro[2] = get_i16(raw + 4);
  sample.accel[0] = get_i16(raw + 6);
  sample.accel[1] = get_i16(raw + 8);
  sample.accel[2] = get_i16(raw + 10);
  return true;
}
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

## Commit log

2026-07-23 Code for running the full sync test pipeline
    Includes:
    - source code for flashing hub, reward port, static daq, laptop command
    sender, and arduino for gpio pulsing
    - source code for log parsing and data analysis
    [adelie_clock_samples.csv, adelie_latency.csv]
2026-07-26 Added ttl generation to sync tests
    - korora schedules galapagos ttl timestamps which get captured by korora
    again
    - changed stying of plots to look pretty
    (also formatted mds)
    [adelie_clock_samples.csv, adelie_latency.csv, reward_port.kicad_pcb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]
2026-07-28 reward port pcb update
    - Schematic update to smaller stm32
    - Pinout update and prototype wiring guide
    - PCB design (4cm x 3cm, 4 layer, components only on front side)
    [PAM8302AASCR_DIO.step, reward_port.kicad_pcb, reward_port.kicad_sch]
2026-07-29 switch to rs485 comms on the sync test
    [adelie_clock_samples.csv, adelie_latency.csv]
2026-07-30 reward port 3d model
    [QFN-28_4x4mm_P0.5mm.step, reward_port.kicad_pcb, reward_port_full.FCStd]
2026-07-30 differential sync (active low switch)
2026-08-05 jlcpcb compatible gerbers, bom and placement
    [bom.csv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]
2026-08-06 small update to exact bulk capacitor, peripheral order list
    [bom.csv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]
2026-08-07 updated order with cables needed
2026-08-07 korora-fairy communication framework
    - implements full firmware for:
    - Hub board korora
    - Peripheral reward port fairy
    - Stationary timing interface galapagos
    - implements full software for control computer (adelie)
    - implements recording analysis
2026-08-11 Reward port electronics design and pcb
    [5015.step, BMD-340-A-R--3DModel-STEP-56544.STEP, NPM1300-CAAA-R--3DModel-STEP-510211.STEP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]
2026-08-11 added 2 sided reward port pcb and jlcpcb order stuff
    [BOM-reward_port.csv, PAM8302AASCR_DIO.step, QFN-28_4x4mm_P0.5mm.step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]
2026-08-12 head sensor kicad
    [A79608-001.step, DFN1006H4-3.stp, UFD_05-08-1711_ADI.step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]
2026-08-13 jlcpcb order for the head sensor
    [bom.csv, designators.csv, head_sensor.kicad_sch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]
2026-08-13 two sided floating platform hub board
    [5015.step, BMD-340-A-R--3DModel-STEP-56544.STEP, BOM-floating_hub.csv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]
2026-08-13 added credit card form
    [260813-Credit_card_purchase_voucher.xls]
2026-08-14 Switching the transistor on floating hub to what was actually ordered
    [head_sensor.kicad_pcb]
2026-08-14 added assets folder for images
    [A79607-001.STEP, A79608-001.step, floating_hub.kicad_pcb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]
2026-08-27 firmware updates for korora PCB
2026-08-31 reward port schematic update to support latching valve as an option
    [reward_port.kicad_pcb, reward_port.kicad_sch]
2026-08-31 firmware updates for pcbs (surprising amount of stuff)
2026-09-02 Removed ttl/event gpio since it's not available on pcbs
2026-10-13 duplicateed the schematics for fairy boards

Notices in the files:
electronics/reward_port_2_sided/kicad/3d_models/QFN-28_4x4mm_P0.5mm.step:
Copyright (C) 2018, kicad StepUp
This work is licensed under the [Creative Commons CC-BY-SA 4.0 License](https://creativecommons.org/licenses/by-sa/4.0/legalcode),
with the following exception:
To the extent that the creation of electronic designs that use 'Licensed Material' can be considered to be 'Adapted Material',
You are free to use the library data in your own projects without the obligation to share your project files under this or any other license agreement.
